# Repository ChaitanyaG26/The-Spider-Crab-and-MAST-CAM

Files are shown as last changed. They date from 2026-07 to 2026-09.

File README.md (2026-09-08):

# The Spider-Crab and MAST-CAM
A rover (rough "Perserverance-replica") equipped with rocker bogie (with a differential bar) suspension, capable of object detection + avoidance (with the RPi AI camera/US-100 sensors), remote control, and autonomous travel (with an onboard GPS). __THERE IS NO PCB ON THIS BUILD. IT IS SOLDERLESS.__ Modeled around the STS-3215 servo. (Special thanks here to Logan Wheatcroft for helping me spell "attach" and getting this project reviewed, and yes, his research project IS real despite what he may say, and of course, SWN from Print Legion for printing everything, alongside my brother -- who "singlehandedly got my project reviewed").

## Table of Contents
- [The Spider-Crab and MAST-CAM](#the-spider-crab-and-mast-cam)
- [Table of Contents](#table-of-contents)
- [Hack-Club Required Q&A](#hack-club-required-qa)
- [Full Assembly Screenshots](#full-assembly-screenshots)
- [BOM](#bom)
- [Printing Instructions](/docs/printing.md)
- [Setting Up The Pi](/docs/electronics-setup.md)
- [Wiring Instructions](/docs/wiring.md)
- [Assembly Instructions](/docs/assembly.md)

## Hack-Club Required Q&A
So, let's see:
1. What is this? This is designed to be a hyper-mobile rover that is capable of autonomous driving, pathfinding (because it is combined with a GPS), and providing camera footage. I hope that I will be able to modify it for usage out of one of two scenarios: 1. hopefully rescue missions on debris/unstable territory (since the rover is pretty lightweight, weighing in at just about 4.5 kgs, and is theoretically capable of some crazy feats as long as the net tractive force is stable), or 2. conducting BAER assessment (providing photos to researchers about theoretically dangerous territories subject to wildfires). If the rover lacks mobility in practice, I will probably move towards the latter concept, in which case I have plans of adding six "sample"-collecting add-ons to be attached to each wheel.
2. Why did I build this? Well, I've always been interested in Aerospace, and I've always thought the Perserverance rover was magical. I'm part of a drone team, and since we just built a drone that was not much unlike Ingenuity, I wondered if I could "complete" the duo here on Earth entirely from my own vision. This rover is the result of that work. I've gone through four separate unique versions of this rover (and even more "micro-versions" where I had to redesign parts inside each version to keep up with out-of-stock products and so on), but the hope is that this final rover will be just as mobile as the rover on Mars, MUCH faster (hopefully going at a mile an hour), WAY less power efficient (but to be fair, I don't exactly have the greatest parts at my disposal), and a final cost JUST under $1000 (so it's affordable), and accessible (meaning it is COMPLETELY idiot-proof -- I should be a good test subject for this, since I have not dealt with PCB design in the LEAST --, and has NO soldering/pcbs involved).

## Full Assembly Screenshots
Okay, before we get started, let's get a few hero renders out of the way.







Eventually, when I build this, I should be able to attach a few "normal" photos of how it'll look. [You may find the final assembly here.](https://cad.onshape.com/documents/4276ee27674d5cd4437829d8/w/b68ed14a30814a824c43fb7e/e/30365733099079a1b69868d1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)

## BOM
Find the BOM above in the attached files.
Or, alternatively, here it is below:

| Quantity | Item | Description | Source | Cost |
| :--- | :---: | :---: | :---: | ---: |
| 24 | [JST 3-Pin to Male](https://www.adafruit.com/product/3893) | Allows for power-injection to the Feetech servos. | Adafruit |  $30.00  |
| 3 | [US-100 Ultrasonic Sensor](https://www.adafruit.com/product/4019) | Allows the rover to navigate terrain/avoid objects. | |  $20.85  |
| 1 | [Pi Camera Cable, 500mm](https://www.adafruit.com/product/5820) | Allows the camera module to freely move. | |  $2.50  |
| 1 | [Raspberry Pi AI Camera*](https://www.adafruit.com/product/6009) | Allows the rover to have object detection/recognition capabilities. | |  $77.00  |
| 1 | [Raspberry Pi 5, 8GB*](https://aaawave.com/products/raspberry-pi-5-development-broad?variant=51441087152449) | The "brains" of the rover. | AAAWave |  $161.63  |
| 1 | [Bus Servo Adapter](https://www.ebay.com/itm/206185697206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) | Allows for the Pi to communicate with the serial bus servos. | eBay |  $12.23  |
| 1 | [microSD Card, A2/V30](https://www.aliexpress.us/item/3256807313581295.html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) | Stores the OS/Firmware on the Pi. | AAAWave |  $29.81  |
| 6 | [Feetech STS3215](https://www.aliexpress.us/item/3256808670629323.html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) | Allows for the rover to move (both its wheels and the camera). | Aliexpress |  $268.65  |
| 1 | [Soldering Iron, HS02A](https://www.aliexpress.us/item/3256809503553320.html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) | Necessary to attach the heat-set inserts, tool. | |  $50.57  |
| 1 | [Hot Air Gun](https://www.aliexpress.us/item/3256810350606440.html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) | Necessary to secure the shrink tubing to properly insulate wires. | |  $7.65  |
| 1 | [Heat Shrink Tubing](https://www.aliexpress.us/item/3256807959988149.html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) | Necessary to electrically insulate certain wires. | |  $6.97  |
| 1 | [WAGO 221-415](https://www.aliexpress.us/item/3256811952946871.html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) | Necessary to proper distribute power as desired. | |  $8.60  |
| 1 | [USB-C/Screw Terminal](https://www.aliexpress.us/item/3256812221028465.html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) | Necessary to provide the RPi power through bare wires. | |  $1.77  |
| 2 | [1M, 12AWG Wire](https://www.aliexpress.us/item/3256808222999562.html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) | Facilitates an electrical connection across parts. | |  $10.86  |
| 1 | [RPi 5, Active Cooler](https://www.amazon.com/dp/B0CW164TCW?ref_=ppx_hzod_title_dt_b_fed_asin_title_0_0) | Allows for smooth Pi operation, prevents overheating. | Amazon |  $9.90  |
| 1 | [12V/30A Daiertek Switch](https://www.amazon.com/dp/B0FL6B75PM?ref_=ppx_hzod_title_dt_b_fed_asin_title_1_0) | A manual power switch for the rover. | |  $29.99  |
| 1 | [20A ANL Fuse](https://www.amazon.com/dp/B01LXQWZ7L?ref_=ppx_hzod_title_dt_b_fed_asin_title_1_1) | Protects electronics downstream. | |  $12.99  |
| 1 | [VK-162 GPS](https://www.amazon.com/dp/B078Y52FGQ?ref_=ppx_hzod_title_dt_b_fed_asin_title_1_2) | Allows the Raspberry Pi to navigate via GPS. | |  $18.98  |
| 1 | [Rod Ends (Small)](https://www.amazon.com/dp/B0828TMYLD?ref_=ppx_hzod_title_dt_b_fed_asin_title_2_0) | Allow for the rocker-bogie suspension to function. | |  $9.99  |
| 1 | [M3x5.7 Heat Set Inserts](https://www.amazon.com/dp/B0D7M4WWBW?ref_=ppx_hzod_title_dt_b_fed_asin_title_2_1) | Allow for the printed parts to be fastened together. | |  $6.47  |
| 1 | [2300 PCS, M3 Screws Kit](https://www.amazon.com/dp/B0FGX859K8?ref_=ppx_hzod_title_dt_b_fed_asin_title_2_2) | Necessary hardware for the assembly to be possible. | |  $21.99  |
| 1 | [Flanged Ball Bearing](https://www.amazon.com/dp/B0G1B7H48R?ref_=ppx_hzod_title_dt_b_fed_asin_title_2_3) | Necessary hardware for the rocker-bogie to be possible. | |  $8.69  |
| 1 | [Jumper Cables](https://www.amazon.com/dp/B07GD2PGY4?ref_=ppx_hzod_title_dt_b_fed_asin_title_2_4) | Allow for power-injection to the daisy-chained servos. | |  $8.99  |
| 2 | [20A/300W Buck Converter](https://www.amazon.com/dp/B099S2VQ2Q?ref_=ppx_hzod_title_dt_b_fed_asin_title_0_0) | Allow for the 12V battery to transfer power downstream. | |  $18.99  |
| 1 | [PTFE/Plumber's Tape](https://www.amazon.com/dp/B091913Z7F?ref_=ppx_hzod_title_dt_b_fed_asin_title_1_0) | Facilitate the physical "bushing" inside the wheels. | |  $3.99  |
| 1 | [12V, 15Ah LiFePO4](https://www.amazon.com/dp/B0CSWMF35Q?ref_=ppx_hzod_title_dt_b_fed_asin_title_1_1) | Powers the rover (hopefully for 2+ hours). | |  $74.99  |
| 1 | [Female Spade Connectors](https://a.co/d/03C3n3lU) | Allow for solderless power supply. | |  $6.99  |
| 1 | [Digital Multimeter](https://www.amazon.com/dp/B08CX9W7G3?ref_=ppx_hzod_title_dt_b_fed_asin_title_0_0) | Checking if the electronic components are viable. | |  $38.43  |
| 1 | [Ring Lugs Set](https://www.amazon.com/dp/B0F99P7SGT?ref_=ppx_hzod_title_dt_b_fed_asin_title_1_0) | Allow for wires to be crimped onto the ANL fuse. | |  $13.99  |
| 1 | [12V LiFePO4 Charger](https://www.amazon.com/dp/B0G3ZNWC4J?ref_=ppx_hzod_title_dt_b_fed_asin_title_1_1) | Charges the battery. | |  $12.19  |
| 1 | [M4x10mm Screws](https://www.amazon.com/dp/B0FH2T8PD1?ref_=ppx_hzod_title_dt_b_fed_asin_title_0_0) | Necessary hardware for the assembly to be possible. | |  $4.30  |
| 1 | [ASA Filament,<br>2kgs (1.2ish needed)](https://www.amazon.com/dp/B0G2L8HKB8?ref_=ppx_hzod_title_dt_b_fed_asin_title_0_0) | Filament for prints. | |  $37.87  |
| 1 | [TPU 95A Filament,<br>1kg (0.8ish needed)](https://www.amazon.com/dp/B07VDP2S3P?ref_=ppx_hzod_title_dt_b_fed_asin_title_0_0) | Filament for prints. | |  $25.97  |
| 1 | [Crimpling "Plier"](https://www.amazon.com/dp/B073YG65N2?ref=ppx_yo2ov_dt_b_fed_asin_title) | Necessary to properly attach the solderless lugs/terminals. | | $8.99 |
| Total: |  |  (with taxes and shipping)  |  |  $1,121.90  |

*Note that for funding purposes, since the Pi and the AI camera are overkill, you can try getting a Pi 4/normal camera module 3 for these. The total cost with these instead would be $994.97ish (which, depending on the version/website you look at, is under $1k!!), and excluding the Pi 5/AI camera is $894.97.

Recommended additional common supplies (double-check you have these):
1. An official raspberry pi 5 power supply (27W).
2. A 12V power supply (preferably 2-3A or less) with a DC5521 power jack.
3. USB to USB-C cable (or a USB to a USB-C female port, and then a USB-C to a USB-C).
4. Micro-HDMI to HDMI cable (this is HIGHLY recommended for setup, because a monitor makes everything easier, although THEORETICALLY you could set up the Pi completely headlessly via SSH).
5. Tape/ruler/marker/etc (these are helpful in construction).

[To be updated as the build proceeds].

## [Printing Instructions](docs/printing.md)
Follow the link above. A quick teaser of what is to come:


## [Setting Up The Pi](docs/electronics-setup.md)
Follow the link above. Another quick teaser:


## [Wiring Instructions](docs/wiring.md)
This is going to be updated once I finalize the wiring, but a teaser as of right now:


## [Assembly Instructions](docs/assembly.md)
[To be created].

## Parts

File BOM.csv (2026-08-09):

Quantity | Item | Description | Manufacturer | Link | Total Cost
24 | JST PH 2mm 3-Pin to Male | Allows for power-injection to the Feetech servos. | Adafruit | https://www.adafruit.com/product/3893 | $ 144.95
3 | US-100 Ultrasonic Sensor | Allows the rover to navigate terrain/avoid objects. |  | https://www.adafruit.com/product/4019
1 | Raspberry Pi Camera Cable, 500mm | Allows the camera module to freely rotate across its axes of freedom. |  | https://www.adafruit.com/product/5820
1 | Raspberry Pi AI Camera | Allows the rover to have object detection/recognition capabilities. |  | https://www.adafruit.com/product/6009
1 | Raspberry Pi 5, 8GB | The "brains" of the rover. | AAAWave | https://aaawave.com/products/raspberry-pi-5-development-broad?variant=51441087152449 | $ 161.63
1 | Waveshare Serial Bus Driver | Allows for the Pi to communicate with the serial bus servos. | eBay | https://www.ebay.com/itm/206185697206?emsid=e11412.m144671.l197929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 | $ 12.23
6 | Feetech STS3215 | Allows for the rover to move (both its wheels and the camera). | Aliexpress | https://www.aliexpress.us/item/3256808670629323.html | $ 404.07
1 | Soldering Iron, HS02A | Necessary to attach the heat-set inserts, tool. |  | https://www.aliexpress.us/item/3256809503553320.html
1 | Hot Air Gun | Necessary to secure the shrink tubing to properly insulate wires. |  | https://www.aliexpress.us/item/3256810350606440.html
1 | Heat Shrink Tubing Kit | Necessary to electrically insulate certain wires. |  | https://www.aliexpress.us/item/3256807959988149.html
1 | WAGO 221-415 Lever Nuts | Necessary to proper distribute power as desired. |  | https://www.aliexpress.us/item/3256811952946871.html
1 | Crimpling "Plier" | Necessary to properly attach the solderless lugs/terminals. |  | https://www.aliexpress.us/item/2251832197019276.html
1 | USB-C to Screw Terminals | Necessary to provide the RPi power through bare wires. |  | https://www.aliexpress.us/item/3256812221028465.html
2 | 1M, 12AWG Wire | Facilitates an electrical connection across parts. |  | https://www.aliexpress.us/item/3256808222999562.html
1 | RPi 5, Active Cooler | Allows for smooth Pi operation, prevents overheating. | Amazon | https://www.amazon.com/dp/B0CW164TCW?ref_=ppx_hzod_title_dt_b_fed_asin_title_0_0 | $ 162.99
1 | 12V, 30A Daiertek Switch | A manual power switch for the rover. |  | https://www.amazon.com/dp/B0FL6B75PM?ref_=ppx_hzod_title_dt_b_fed_asin_title_1_0
1 | 20A ANL Fuse (and Holder) | Protects electronics downstream. |  | https://www.amazon.com/dp/B01LXQWZ7L?ref_=ppx_hzod_title_dt_b_fed_asin_title_1_1
1 | VK-162 GPS | Allows the Raspberry Pi to navigate via GPS. |  | https://www.amazon.com/dp/B078Y52FGQ?ref_=ppx_hzod_title_dt_b_fed_asin_title_1_2
1 | Rod Ends (Small) | Allow for the rocker-bogie suspension to function. |  | https://www.amazon.com/dp/B0828TMYLD?ref_=ppx_hzod_title_dt_b_fed_asin_title_2_0
1 | 120PCS, M3x5.7 Heat Set Inserts | Allow for the printed parts to be fastened together. |  | https://www.amazon.com/dp/B0D7M4WWBW?ref_=ppx_hzod_title_dt_b_fed_asin_title_2_1
1 | 2300 PCS, M3 Screws Kit | Necessary hardware for the assembly to be possible. |  | https://www.amazon.com/dp/B0FGX859K8?ref_=ppx_hzod_title_dt_b_fed_asin_title_2_2
1 | Flanged Ball Bearing | Necessary hardware for the rocker-bogie to be possible. |  | https://www.amazon.com/dp/B0G1B7H48R?ref_=ppx_hzod_title_dt_b_fed_asin_title_2_3
1 | Breadboard Jumper Wires | Allow for power-injection to the daisy-chained servos. |  | https://www.amazon.com/dp/B07GD2PGY4?ref_=ppx_hzod_title_dt_b_fed_asin_title_2_4
2 | Adjustable DC Buck Converter | Allow for the 12V battery to transfer power downstream. |  | https://www.amazon.com/dp/B099S2VQ2Q?ref_=ppx_hzod_title_dt_b_fed_asin_title_0_0 | $ 129.46
1 | PTFE/Plumber's Tape | Facilitate the physical "bushing" inside the wheels. |  | https://www.amazon.com/dp/B091913Z7F?ref_=ppx_hzod_title_dt_b_fed_asin_title_1_0
1 | 12V, 15Ah LiFePO4 | Powers the rover (hopefully for 2+ hours). |  | https://www.amazon.com/dp/B0CSWMF35Q?ref_=ppx_hzod_title_dt_b_fed_asin_title_1_1
1 | Spade Terminal Connectors | Allow for power to be transmitted from the battery downstream solderlessly. |  | https://www.amazon.com/dp/B0B4H54KPS?ref_=ppx_hzod_title_dt_b_fed_asin_title_2_0
1 | Digital Multimeter | Checking if the electronic components are viable. |  | https://www.amazon.com/dp/B08CX9W7G3?ref_=ppx_hzod_title_dt_b_fed_asin_title_0_0 | $ 38.43
1 | Ring Lugs Set | Allow for wires to be crimped onto the ANL fuse. |  | https://www.amazon.com/dp/B0F99P7SGT?ref_=ppx_hzod_title_dt_b_fed_asin_title_1_0
1 | 12V LiFePO4 Charger | Charges the battery. |  | https://www.amazon.com/dp/B0G3ZNWC4J?ref_=ppx_hzod_title_dt_b_fed_asin_title_1_1
1 | M4x10mm Screws | Necessary hardware for the assembly to be possible. |  | https://www.amazon.com/dp/B0FH2T8PD1?ref_=ppx_hzod_title_dt_b_fed_asin_title_0_0 | $ 4.30
1 | ASA Filament, 2kgs (1.2ish needed) | Filament for prints. |  | https://www.amazon.com/dp/B0G2L8HKB8?ref_=ppx_hzod_title_dt_b_fed_asin_title_0_0 | $ 37.87
1 | TPU 95A Filament, 1g (0.8ish needed) | Filament for prints. |  | https://www.amazon.com/dp/B07VDP2S3P?ref_=ppx_hzod_title_dt_b_fed_asin_title_0_0 | $ 25.97
Total: |  |  |  |  | $ 1,121.90

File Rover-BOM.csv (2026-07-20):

Quantity | Item | Description | Manufacturer | Link | Cost (No Tax/Shipping)
12 | Servo | Powers the wheels and the camera module. | WOWROBO | https://shop.wowrobo.com/products/feetech-sts3215-servo-12v-30kg-high-torque-servo-for-so-arm100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 | $ 171.88
1 | RPi5/8GB | Powers the camera module, controls the rover. The "brains." | AAAWave | https://aaawave.com/products/raspberry-pi-5-development-broad?variant=51441087152449 | $ 150.00
1 | MicroSD | High-powered SD card for video streaming. | Sandisk | https://www.sandisk.com/products/memory-cards/microsd-cards/sandisk-extreme-uhs-i-microsd?sku=SDSQXAH-064G-GN6MA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 | $ 25.99
1 | RPi Active Cooler | Provides cooling (improving performance) to the RPi. | Waveshare | https://www.waveshare.com/pi5-active-cooler-b.htm | $ 4.99
1 | Servo Driver HAT | Allows the RPi to control the servos. |  | https://www.waveshare.com/bus-servo-driver-hat-a.htm | $ 18.99
1 | RPi AI Camera | Allows the RPi to run object detection/livestreaming. | Adafruit | https://www.adafruit.com/product/6009?src=raspberrypi | $ 77.00
1 | Camera Cable - 500mm | Extends the camera module's range. |  | https://www.adafruit.com/product/5820 | $ 2.50
3 | US-100 Sensor | Allows the RPi to run object avoidance. |  | https://www.adafruit.com/product/4019 | $ 20.85
1 | Stacking Header, GPIO | Allows the HAT to be attached onto the Pi alongside the Active Cooler. |  | https://www.adafruit.com/product/2223 | $ 2.95
12 | Male to JST-PH Wires | Allows for the solderless wiring (acting as a breakout board for power-injection). |  | https://www.adafruit.com/product/3893 | $ 15.00
12 | Female to JST-PH | Same role as the male wires, composite. | Electromaker | https://www.electromaker.io/shop/product/stemma-jst-ph-3-pin-to-female-socket-cable-200mm | $ 15.00
1 | Ball Bearings | Facilitate the rocker-bogie's rotational freedom. | Amazon | https://www.amazon.com/uxcell-F6901ZZ-Flanged-Bearings-Shielded/dp/B0G1B7H48R?sp_csd=d2lkZ2V0TmFtZT1zcF9tdGY | $ 7.82
1 | VK-162 | Allow the RPi to gain GPS-based autonomous capabilities. |  | https://www.amazon.com/Navigation-External-Receiver-Raspberry-Geekstory/dp/B078Y52FGQ | $ 17.98
1 | LiFePO4 12V 15Ah Battery | Powers the rover. |  | https://www.amazon.com/12-8V-20Ah-LiFePO4-Battery-Lithium/dp/B0DHKS1GK6 | $ 53.19
1 | LiFePO4 Charger | Charges the battery. |  | https://www.amazon.com/dp/B078962VRM?s=automotive&sp_csd=d2lkZ2V0TmFtZT1zcF9kZXRhaWxfdGhlbWF0aWM | $ 25.07
1 | WAGO 221-415 (25 Pack) | Facilitate the solderless connections with the power gauge wire and the Male/Females. |  | https://www.amazon.com/WAGO-221-415-Lever-Nuts-5-Conductor-Connectors/dp/B07WC2XBMK | $ 17.99
1 | Breadboard Jumper Wires Set | To extend the Male/Female JST-PH wires. |  | https://www.amazon.com/EDGELEC-Breadboard-Optional-Assorted-Multicolored/dp/B07GD2PGY4?s=industrial | $ 8.99
1 | Heat Shrink Tubing Set | Allow for the solderless collections to be solid. |  | https://www.amazon.com/Eventronic-560-Heat-Shrink-Tubing/dp/B0DK15C58W?s=hi&sp_csd=d2lkZ2V0TmFtZT1zcF9hdGY | $ 13.59
1 | Mini Heat Gun | Combine with the Heat Shrink Tubing |  | https://www.amazon.com/QWORK-Shrink-Shrinking-Wrapping-Embossing/dp/B09NDCCW29?s=hi | $ 8.72
2 | 20A 300W Adjustable Buck Converter | Allows for the power source to safely distribute power to the Pi/Servos. |  | https://www.amazon.ca/XLX-High-Power-Converter-Adjustable-Protection/dp/B081X5YX8V | $ 31.98
1 | 20A ANL Fuse | Protects the inner circuitry. |  | https://www.amazon.com/RENOGY-30A-ANL-Fuse-Holder/dp/B01LXQWZ7L | $ 12.99
1 | Spade Terminal Connectors | Allow for a solderless connection to the battery. |  | https://www.amazon.com/Feggizuli-Connectors-Connector-Terminals-Electrical/dp/B0B4H54KPS | $ 7.69
1 | 12 Gauge Wire | Allow for power streaming over long-distance power injection. |  | https://www.amazon.com/Voltage-Automotive-Primary-Security-Electrical/dp/B0D97CJYY7?rnid=1243644011 | $ 11.99
1 | Rod-End Set | Allows for the Differential Mechanism to function. |  | https://www.amazon.com/Que-T-10pcs-Metal-Crawler-Silver/dp/B0828TMYLD?s=toys-and-games | $ 9.99
1 | M3 Screw/Nut Set | Required for the multipart assembly. |  | https://www.amazon.com/Fgruh-2300PCS-M3-Assortment-Washers/dp/B0FGX859K8?sp_csd=d2lkZ2V0TmFtZT1zcF9hdGY | $ 21.99
1 | Plumber's Tape | Alternative to bushing, bridge the ASA with low frictional losses. |  | https://www.amazon.com/Inches-Plumbers-Plumbing-Plumber-Sealing/dp/B0919T7JV1?sp_csd=d2lkZ2V0TmFtZT1zcF9hdGY | $ 7.39
1 | Heat-Set Inserts | Required for the multipart assembly. |  | https://www.amazon.com/Threaded-Inserts-M3x5-7x4-6-Soldering-Materials/dp/B0D7M4WWBW | $ 6.27
1 | Soldering Tin | Required for the stacking header soldering. |  | https://www.amazon.com/MAIYUM-63-37-Solder-Electrical-Soldering/dp/B075WB98FJ?sp_csd=d2lkZ2V0TmFtZT1zcF9hdGY | $ 8.99
1 | Soldering Iron | Required for the Heat-Set Inserts and the Soldering. | Aliexpress | https://www.aliexpress.us/item/3256809503461511.html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 | $ 31.38
Total: |  |  |  |  | $ 809.16
Total (*with taxes and shipping): |  |  |  |  | $ 1,000.00
Total (*with taxes and shipping AND prints): |  |  |  |  | $ 1,350.00

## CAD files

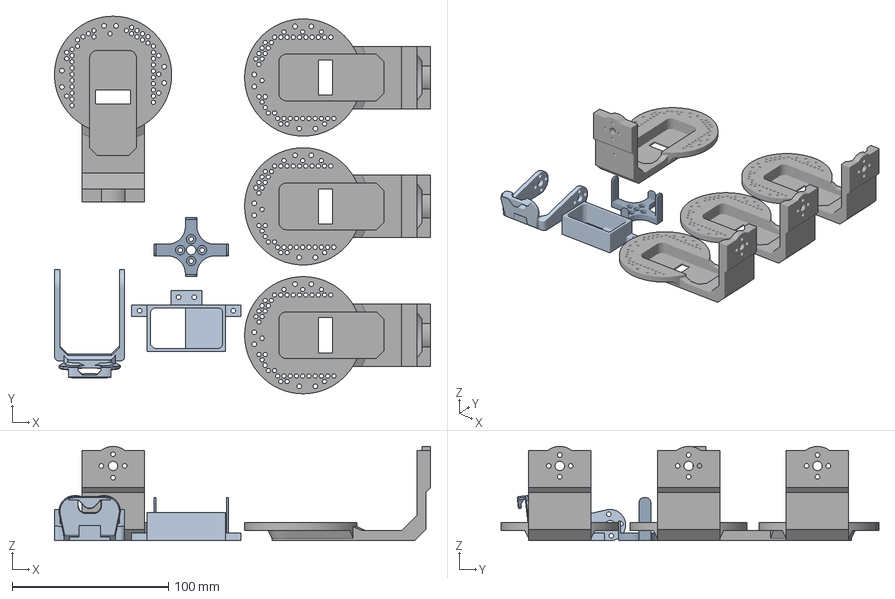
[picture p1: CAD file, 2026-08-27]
3MF Files/ASA_#4_20%_3d-cubic_2walls.3mf
240.7 x 241.7 x 60.3 mm
Servo Base
Arm x 4
S-S/C
C-S/C

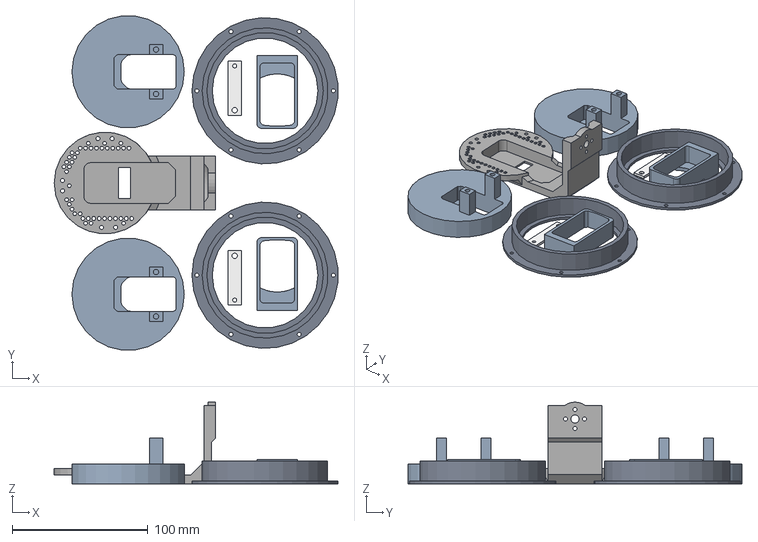
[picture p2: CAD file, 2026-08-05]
STEP Files/Build Plates/Build_Plate-1-and-2-ASA.step
209.1 x 246.3 x 60.3 mm

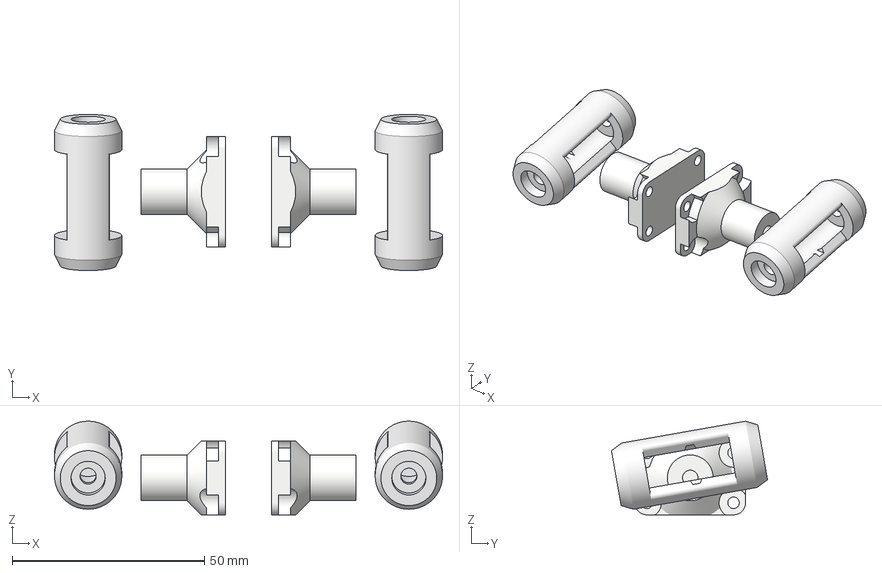
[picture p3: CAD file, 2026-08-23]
3MF Files/ASA_#9_50%_3d-cubic_4walls.3mf
100.9 x 40.6 x 24.4 mm
CRBC x 2
DRE/C x 2

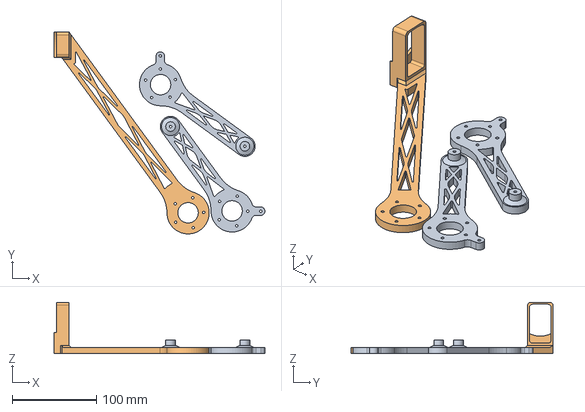
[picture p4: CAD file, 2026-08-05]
STEP Files/Build Plates/Build_Plate-7-ASA.step
250.8 x 239.9 x 61.1 mm

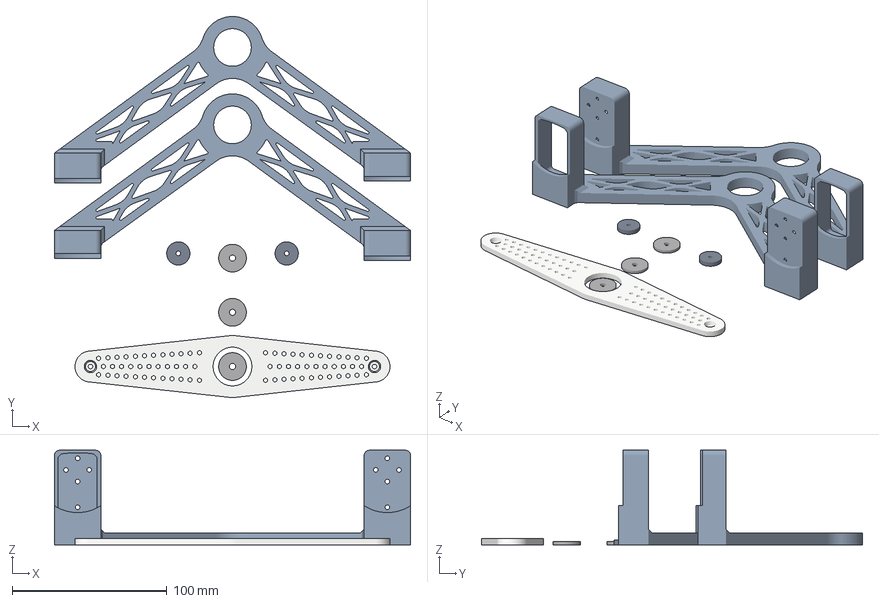
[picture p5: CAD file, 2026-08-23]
3MF Files/ASA_#6_20%_3d-cubic_2walls.3mf
230.0 x 246.0 x 61.1 mm
Bogie/R
BB/C/F x 3
BBSL/F
Bogie/L
BBSR/F
Differential Bar

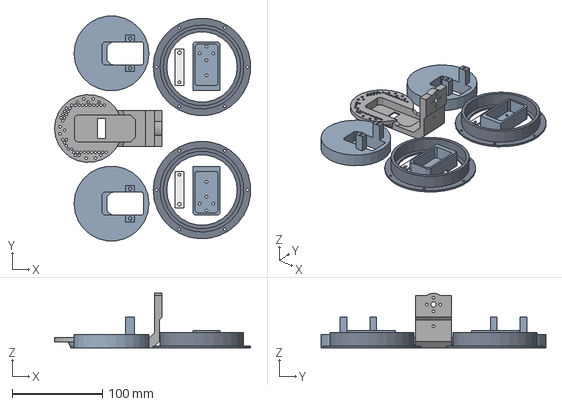
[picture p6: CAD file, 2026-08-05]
STEP Files/Build Plates/Build_Plate-3-ASA.step
216.6 x 248.3 x 60.3 mm

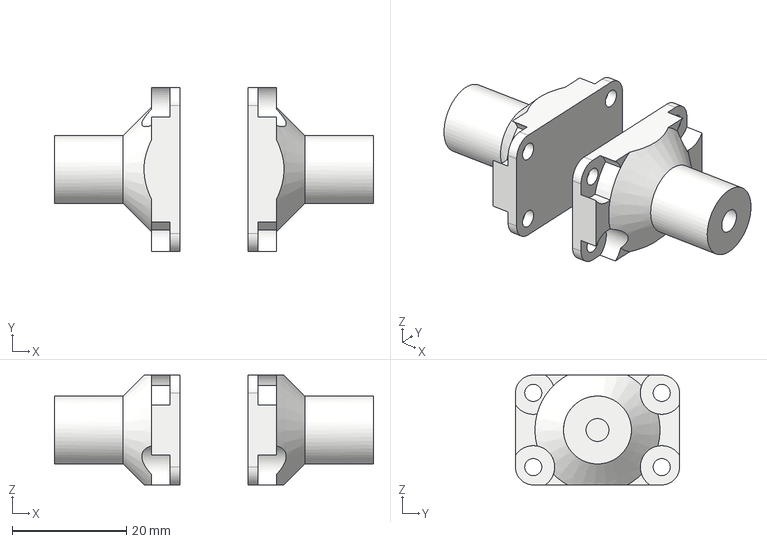
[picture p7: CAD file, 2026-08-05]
STEP Files/Build Plates/Build_Plate-9-ASA.step
55.9 x 28.7 x 19.2 mm

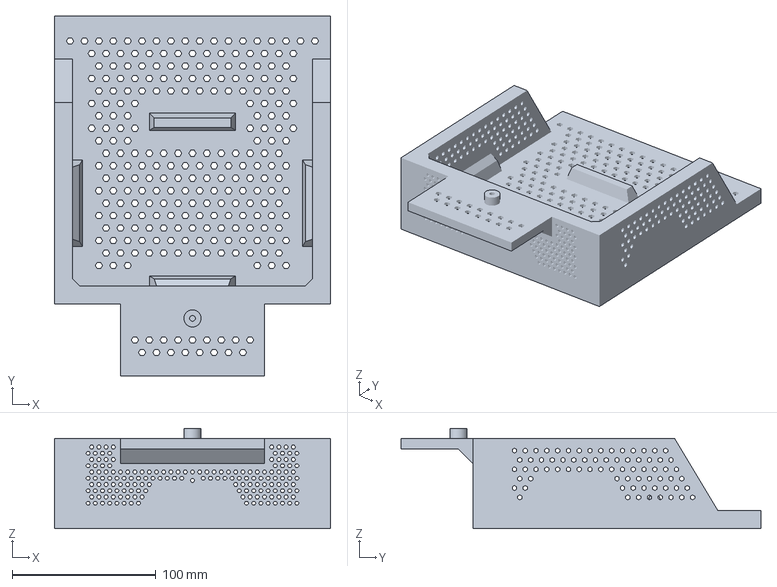
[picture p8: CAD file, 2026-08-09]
3MF Files/ASA_#5_15%_3d-cubic_2walls.3mf
191.9 x 250.0 x 69.7 mm

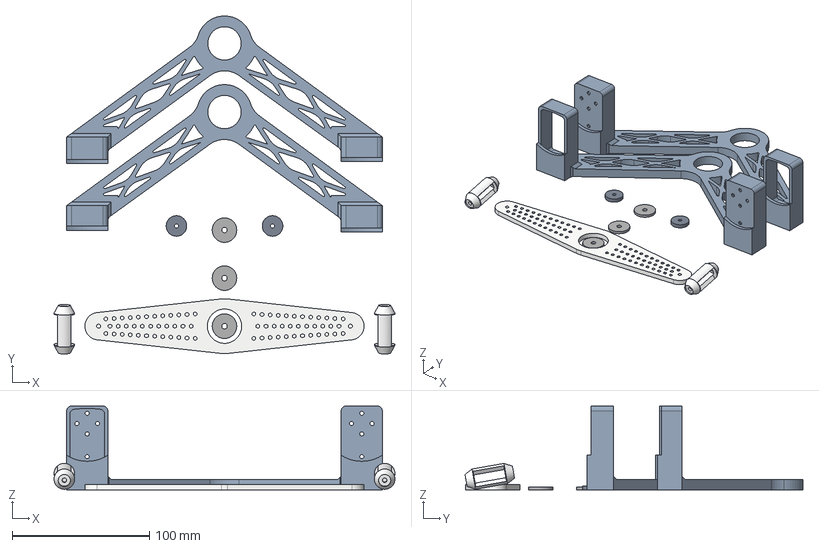
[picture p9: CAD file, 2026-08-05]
STEP Files/Build Plates/Build_Plate-6-ASA.step
248.4 x 246.2 x 61.1 mm

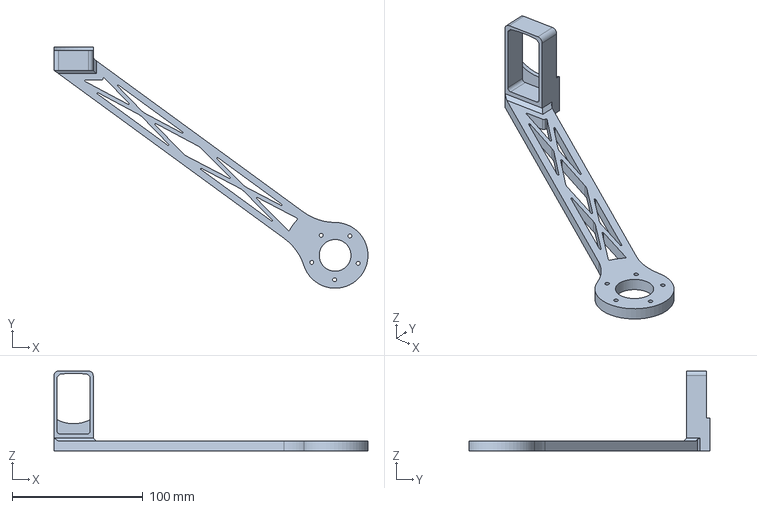
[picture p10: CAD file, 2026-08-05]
STEP Files/Build Plates/Build_Plate-8-ASA.step
239.9 x 184.5 x 61.1 mm

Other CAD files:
3MF Files/TPU_#1_15%_gyroid_6wallsmodifiers_2walls.3mf
STEP Files/Build Plates/Build_Plate-4-ASA.step
3MF Files/ASA_#3_20%_3d-cubic_2walls.3mf
3MF Files/ASA_#7_20%_3d-cubic_2walls.3mf
3MF Files/ASA_#2_20%_3d-cubic_2walls.3mf
3MF Files/ASA_#1_20%_3d-cubic_2walls.3mf
3MF Files/ASA_#8_20%_3d-cubic_2walls.3mf

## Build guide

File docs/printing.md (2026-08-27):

## Printing Instructions

PLEASE PLEASE PLEASE make it easy on yourself and use the 3MF **NOT** the STEP files for actually uploading onto a slicer.
Whenever you load the part, make sure that if you get the following screen, you click **yes**:


If you look at the naming convention for each 3MF files, it is clearly explained what settings are recommended (IE, ASA_#9_20%_3d-cubic\_4walls should be printed in ASA at 20% infill in a cubic sparse infill pattern with 4 walls). Now, this does get more complicated with the TPU. The TPU 3MF files include simple cylinders positioned around holes. These cylinders are modifiers. ***While the rest of the print is to be at 15% gyroid infill with 2 walls, these modifiers should be changed to SIX walls.*** This is VERY crucial. Heat Set Inserts are very annoying with TPU (as I've heard), and for them to be properly fastened/secured, the TPU must be made rigid. To save your time and filament whilst making heat-sets viable, these modifiers are meant to circle each cylindrical hole, providing enough material for the heat-set inserts to properly bite into the thermoplastic. If everything goes right, you should expect around 545g worth of filament being used for TPU\_1. Keep supports on for all prints.

### Adding Modifiers to a Print:


Note that the provided settings are the basic settings. If you have other settings for supports, etc, you may use those (as those do not impact strength).

IN TOTAL YOU MAY EXPECT: 817.79g TPU being used (this is with supports) over 51.64 hours of printing. 1107.18g ASA being used (this is also with supports) over 56.67 hours of printing, for a total of around 108.31 hours of printing.

Tolerances are in-built into the prints, so long as everything is printed in the right material (ASA or TPU), as outlined. Remember, any other materials would either be more expensive alternatives, or less viable ones (ie, TPU is the best filament here because it is relatively common, flexible, but has a high temperature deflection point relative to the use-case the rover is ideal for, and ASA is the best rigid common filament with another reasonable temperature deflection point). You can see the overall assembly at this [link](https://cad.onshape.com/documents/4276ee27674d5cd4437829d8/w/b68ed14a30814a824c43fb7e/e/30365733099079a1b69868d1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). navigate to "The Spyder-Crab", and then the assembly of the same name), and simply hide the relevant objects to see precisely where everything goes.

Since there's so many parts (600 by my estimation), I will NOT be going over how each of the parts fit, although I believe most of it is obvious: in general, holes of diameter 4mm have a heat-set insert, holes of diamter 3mm allow for M3 screws to be passed, and so on. There are other specific cut-outs for flanged ball bearings (and so on for other parts, such as the rod-end).

Photos of the print plates:
### ASA #1 AND #2 (remember, these are the EXACT same plate, but one of the two needs to be printed twice or **BOTH NEED TO BE PRINTED ONCE EACH**):


### ASA #3:


### ASA #4:


### ASA #5:


### ASA #6:


### ASA #7:


### ASA #8:


### ASA #9:


### TPU #1:


### TPU #2:


Eventually, I will make a complete tutorial for how the rover will be built (step-by-step), with photos (or a video).

[Go back home.](/README.md)

[Onto the next tutorial!](/docs/electronics-setup.md)

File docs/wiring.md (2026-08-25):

## Wiring Instructions
TL;DR WIRING DIAGRAMS: I would HIGHLY recommend reading the next bits of text for a full tutorial on how to wire everything, but here are three "brief" wiring diagrams showcasing how everything will work.
Schematic1
Schematic2


THE ROVER IS COMPLETELY SOLDERLESS. IT IS DESIGNED TO NOT REQUIRE A PCB, BUT RATHER EASILY SOURCED PARTS ONLINE. There is nothing but a bit of cutting wires/sliding them into screw terminals or WAGO lever nuts. The rough diagram can be seen in the following image, subject to change (as soon as I build it and test it myself).





##### A GENERAL WARNING AND/OR A WORD TO NOTE BEFORE WE BEGIN. UNLESS YOU ARE TESTING YOUR CIRCUIT, DISCONNECT IT FROM THE BATTERY. IT DOES NOT MATTER IF THE POWER SWITCH IS OFF, OR EVEN THE BUCK CONVERTER'S SWITCH, IF THE BATTERY IS CONNECTED POWER CAN BE STORED IN THE BUCK CONVERTER'S CAPACITOR AND A) POWER WILL DRAIN FASTER THAN YOU THINK AND B) YOU MIGHT HAVE SPARKS WHILE YOU ATTACH YOUR COMPONENTS. WHENEVER YOU ATTACH SOMETHING, MAKE SURE THE POWER IS OFF. WHENEVER TURNING OFF POWER, START DOWNSTREAM UP (THE POWER SWITCH, THEN THE BUCK CONVERTER, THAN THE SPADE TERMINAL CONNECTORS THEMSELVES -- MAKING SURE TO TOUCH THE _PLASTIC_ NOT THE METAL TO RISK INJURY).

##### WHEN WORKING WITH STRIPPING THESE WIRES, I HIGHLY RECOMMEND USING THE STRIPPING TOOL TO MAKE AN INCISION THREE QUARTERS OF A FINGERNAIL FROM THE EDGE, AND THEN USING A SEPARATE BLADE TO FULLY REMOVE THE INSULATING PLASTIC LAYER (SINCE THE WIRE IS FINELY STRANDED, ANY MAJOR INCISION/TUGGING WITH THE WIRE STRIPPER WOULD SEVERELY DAMAGE THE WIRE BY REMOVING ITS STRANDS). I ALSO HIGHLY RECOMMEND SEATING EACH WIRE INTO THE YELLLOW ATTACHMENT AS MUCH AS POSSIBLE BEFORE CRIMPING ON THE BOTTOM PART (AND ON THE CENTER PART): IE, AS IN THE EXAMPLE BELOW, WHERE YOU CAN SEE __TWO__ MARKS FROM THE CRIMPING TOOL. I ALSO HIGHLY RECOMMEND TWIRLING THE WIRE A BIT (NOT TWISTING, SINCE THAT CAN ALSO DAMAGE THE WIRE, BUT "COMPACTING THEM" THROUGH SMALLER ROTATIONAL MOVEMENT) BEFORE SEATING INTO THE WAGO LEVER NUTS (WHERE THEY MUST BE PUSHED IN AS FAR IN AS POSSIBLE).



As you can see here, this is the rough wiring layout. Connect the battery to crimped spade terminal wires (6-12 gauge), connect the other end to an ANL fuse (with ring lugs, again, crimped), to the power switch and then the buck converter (set at 12V). Route the wire from the buck converter to three separate lines via the WAGO (respectively), to the Pi, and to the servo power lines. The rest of the diagram can be read as follows. Remember, there must be power injection with the servos on top of the star topography, as there would be significant browning near stall. This can be done by taking each male-JST connector, and directing that to a female-female wire, and leading that to another male-JST connector (keeping the ground and signal wires the same, but exchanging the hot/positive lead for a voltage line out of another WAGO lever nut. Once I build this, I will add photos and a detailed guide of how this can be accomplished (after all, right now this is just all theoretical). Soon, everything should be up! Right now, it is as bare-bones as it gets, but I should have this sorted out in just a little bit of time.

Okay, so getting started with wiring. Remember to charge your battery while you set up everything (I recommend cutting up a few wires and beginning to strip them while you wait for the battery to charge a bit, although it ships near 50% so you can also get started immediately on this starter circuit).
Note that I call this a "starter circuit." It has the exact same wiring layout as the official wiring for the rover, but you haven't gotten to that yet so this is simply an incremental test to ensure all the parts work. You are to use no more than 1M of the wire (because the remaining meter will be used for the actual rover).



This is the "end result" before power injection, which is a WHOLE issue in of itself. We'll work our way up to it.
Firstly, two wires need to be crimped with a female spade terminal so everything fits nicely. You can see the spade terminals as the small yellow flat things. One of these will connect to the battery's positive lead, one to the ground or negative one. The 20A ANL fuse will connect DIRECTLY to the battery's positive lead via one of the two wires above, while the GND wire will go down the battery into one of the buck converters (you have three, pick one and wire the GND to it's IN- screw terminal). Meanwhile, the other end of the ANL fuse will lead to the IN+ screw terminal. It is at this point, you may take your multimeter and place its red lead in the Voltage port (usually, multimeters have three ports, I recommend the one labeled something along the lines of "mA") and the black lead in the COM port



You may then place the red/positive lead into the OUT+ screw terminal and the black/negative lead into the OUT- screw terminal. Adjust CV (with a screwdriver) until you get a number roughly around 12V. This will serve as the power for your servo. Then, disconnect it when you are done.

Now, after that, your OUT+ lead of the buck converter will connect directly to one end of your Daiertek power switch (stripped, of course). The OUT- lead of the buck converter will connect directly to a GND wire. To understand why this specific layout was chosen, you need to understand: you provide power with the hot lead (the positive side) which carries current through an electric potential (a difference in voltage). Your goal, for all your electronics, is to make sure the positive lead wires somehow through a part, and then current flows from that positive lead to a negative or a ground port on that same part (where the voltage drop between the positive and negative ports allows for your current flow) and powers your device. Your power switch, by connecting to the buck converter and a WAGO lever nut, creates a "power rail," where any wire connected to that and a part which is similarly connected the "ground rail" (which your ground wire, which is connected to the OUT- of the buck converter and its own WAGO lever nut) and power can be provided. There are four red wires that connect to the power rail (ie, distribute power): the first is connected to another buck converter's IN+ lead (one that is to be used to provide power to the Raspberry Pi), and the other three are connected to their own WAGO lever nut (where, from each WAGO lever nut, power will be supplied to the appropriate servo, power injection, which can be seen through the image below). There are four black wires that connect to the ground rail, for the same reason: one acts as ground for the buck converter (and is inserter to the IN- lead), and three others connect to WAGO lever nuts to distribute ground to each servo. A common ground between the servo, after all, is necessary: the signals the bus servo adapter provides depend heavily on the voltage difference between the hot and ground leads, so a common voltage source MUST be accompanied by a common ground. You may fine tune the buck converter here so that you set 5V (or a slightly higher value, maybe 5.05 or 5.1V) as the CV on the second buck converter. The remaining slots are for wires that will directly go to the serial bus servos (not modeled here, but included in the image above, since I highly recommend NOT doing this step until you are absolutely positive everything is perfect).



You may wonder why this "power injection" is even necessary. In a daisy-chained configuration, all current required downstream is pulled upstream. When there is only one source, all this current goes through the VERY THIN JST PH wires (which are scarcely rated for more than 3A) and severe voltage browning occurs (ie, power is lost and suddenly, none of your servos are moving when you need them too). You need to make sure each servo gets its own independent power, and this reduces current through wire and ensures everything is fine. According to Waveshare, using the bus servo adapter in this way (to only run signals) is perfectly acceptable and extremely common (and thus, requires no major change in the code). The goal is, then, to make sure GND and the HOT leads are similarly _shared_ (ie, they are from the same source and maintain the same relative voltage difference, so that signals are accurate, which is why a single major power/gnd rail is created -- a "common" source allows for GND to be shared, and similarly for the HOT lead) and _individual_ (ie, no more than 2A every goes through ANY of the wires -- and if so, only for small amounts of time and VERY short distances).

Once you are done with your test circuit, I highly recommend waiting for prints and finishing [assembly](/docs/assembly.md), or at the VERY LEAST, finishing the [electronics set-up](/docs/electronics-setup.md) before beginning your official build so all of the wires can be cut to size and so you can properly place all of your electronics wherever you have space (or, for that matter, need to place them) on the build. Part of the reason for the MANY MANY MANY hex cut-outs (instead of simply reducing weight, something possible through a basic infill pattern such as 3d-honeycomb, cubic, or gyroid) is so electronics can be gently secured via screws and the multiple through holes.



But either way, I recommend starting in this manner, where your ANL fuse is parallel to the battery to save space and so your wires have minimal questionable contact and bending (no wire undergoes copious amounts of stress).

[Go back home.](/README.md)

[Onto the next tutorial!](/docs/assembly.md)

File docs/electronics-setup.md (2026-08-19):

## Setting Up The Pi
Note that this step should take place BEFORE the wiring is finalized (ie, the servos are included in the wiring), so everything can be tested properly and debugged (at least everything relevant to the coding), or, alternatively, before the wiring altogether.


A quick preview at what y'all are getting into.

Downloading the Imager.
Take your SD card, and plug into your computer. Try using either a computer with an SD card slot (with the microSD card in its SD card "sleeve") or get a USB-SD card reader.
1. Choose the Raspberry Pi 5 as the device.


2. Choose the default software (the Raspberry Pi 8GB can tolerate the 64-bit Raspberry Pi OS).


3. Choose your storage device as the SD card (which should be inserted into your computer).

4. Give the device a hostname/username/password you will remember. Write this down (it'll save you later).
5. If you get a dialog to connect to a network, provide your home wifi (and password, of course).
6. Enable SSH. You can enable a public SSH key, but I find that the password authentication setup is easier.
7. Flash your imager onto the appropriate storage device (the SD card you just plugged in).
8. Remove your SD card and plug that into the Raspberry Pi 5.
9. Connect the Raspberry Pi 5 to a monitor via a Micro-HDMI to an HDMI cable.

Setting up the Pi on Boot:
1. Once you are logged in, you can begin by setting up the VK-162. This is probably the easiest part of the setup.
    1. Plug in the VK-162 to a USB slot on the Raspberry Pi.
    2. Check the VK-162 is there with the command `ls /dev/ttyACM*` in the Raspberry Pi's CLI. The output            should be `dev/ttyACM0`
    3. Run `lsusb | grep -i "u-blox"` The result should be `Bus 003 Device 002: ID 1546:01a7 U-Blox AG`
       `[u-blox 7]` or an equivalent.
    4. Install gpsd:
       `sudo apt update`, then `sudo apt install -y gpsd gpsd-clients python3-gps`
    5. Configure gpsd:
       `sudo nano /etc/default/gpsd`, you must add: `DEVICES="/dev/ttyACM0"`, `GPSD_OPTIONS="-n"`, `START_DAEMON="true"`, and `USBAUTO="true"`
    6. Restart and test: `sudo systemctl restart gpsd`, then `cgps -s`  


2. If you want to, you can change the fan settings.
     1. Type `sudo nano /boot/firmware/config.txt` into the CLI.
     2. Scroll to the very bottom and add the lines below:
        `dtparam=fan_temp0=40000`
        `dtparam=fan_temp1=45000`
        `dtparam=fan_temp2=50000`
        `dtparam=fan_temp3=55000`
        `dtparam=uart0=on`
3. Setting up the Raspberry Pi AI Camera:
    1. The black side on the Pi is on the opposite side from the USB ports, whilst the black side on the Camera faces on the opposite side from the main camera module. Wire in this fashion. Tweezers are helpful.
    2. Run `sudo apt update && sudo apt full-upgrade`
    3. Run `sudo reboot`
    4. Run `rpicam-hello -t 0s --post-process-file /usr/share/rpi-camera-assets/imx500_mobilenet_ssd.json --viewfinder-width 1920 --viewfinder-height 1080 --framerate 30` This should return a live feed with post-processed object detection
    5. Run `rpicam-hello -t 0s --post-process-file /usr/share/rpi-camera-assets/imx500_posenet.json --viewfinder-width 1920 --viewfinder-height 1080 --framerate 30` This should return a live feed with post-processed pose detection.
    6. If you wish to change the focal length (and thus the focus), take the plastic knob, point the hollow end towards the camera module, press, and turn. Test out various focal lengths (but be careful as to not damage the electronic) through the hole until you find an appropriate one.
  


Kudos if your screen also looks something like this.

4. Setting up the __FIRST__ STS3215 Servo:
    1. Connect the servo horns to each servo. Usually, you can simply push into the toothed brass attachment until the horn is flush with the bottom and a click is heard. If the horn is refusing to be attached properly, use your thumb to push until you seat the horn a bit into the tooth (you can tell this is the case if you leave your hand and the horn doesn't move). Then, use your palm to connect it until a loud click is heard. The tolerances are so tight that the latter technique is often necessary (and in my experience the best one). Screw in everything (but leave a bit of leeway, so the horn is stable but the screw can still "wiggle" a bit).
    2. Make sure your bus servo adapter has the yellow jumpers set to "B" as labeled on the board. Find a USB to a USB-C cable. If you do not have one, a traditional USB to a USB-C female socket is acceptable when connected with a USB-C to a USB-C cable (in fact, the latter architecture is the one I chose). Attach the USB-C port to the bus servo adapter, and the USB to the Pi. Wire a servo through one of the JST ports to the servo's JST port (just be careful for the orientation). Plug in your bus servo adapter with a DC5521 power jack (connected to a 12V power supply for setup). Wait a few seconds, and then run `dmesg | tail -1`. Remember this, this is the port you will use in Step 8.
    3. Label the serial bus servo you have just plugged in with tape and a marker as 1. This is your servo ID (which must be unique for EACH of the 12 servos to allow for a functioning daisy-chain network). Label the rest of the 12 servos with similar numbering. You will label each servo with that ID during the following setup.
    4. Run `sudo apt update && sudo apt install unrar -y` This downloads a program capable of unzipping rar files on Linux (which is the format provided by Waveshare's ST-series servos).
    5. [Download the Waveshare ST-series Python control library.](https://files.waveshare.com/wiki/Bus_Servo_Driver_HAT_A/SCServo_Linux.rar) This will be the code that will help you setup the serial bus servos. Download onto a predetermined location, and then run `unrar x SCServo_Linux.rar` This will unzip the file, allowing for setup. Then, run `sudo apt install cmake -y` CMake will be the application that actually sets up your code and allows you to control the servos.
    6. Then, open your SCServoLinux file in a new terminal (right click the SCServoLinux file -inside the SCServoLinux_220329, and then click "Open in Terminal"). Then, run `cmake .` Then, run `make SCServo` It should say "[100%] Built target SCServo"
    7. Then, type in `cd examples/SMS_STS/WritePos` Run `nano WritePos.cpp` Change the 17th line to say "1000000" instead of "115200." This is the servo's baud rate, and it is 1000000 (the hardcoded value is wrong). Run Ctrl+O, click Enter, then run Ctrl+X. Now, you may run `cmake .` and then `make WritePos`
    8. Go back to the port from Step 2. Run `sudo ./WritePos [port]`, where your final command should look like `sudo ./WritePos /dev/ttyACM2` When you want this to stop, you can run Ctrl+C. Your servo should spin.



5. Setting up __THE SECOND__ Servo:
    1. Disconnect power from the serial bus servo adapter and the USB-C cable connecting the board to the Pi. Once power is off, disconnect the first serial bus servo and replace it for the one labeled "2" and wire that.
    2. Run `mkdir ~/SCServo_Linux_220329/SCServo_Linux/examples/SMS_STS/ChangeID` Find the ChangeID.cpp file attached above and drop it into the newly created ChangeID folder.
    3. Run:
       ```
       cp ~/SCServo_Linux_220329/SCServo_Linux/examples/SMS_STS/WritePos/CMakeLists.txt \
       ~/SCServo_Linux_220329/SCServo_Linux/examples/SMS_STS/ChangeID/
       cd ~/SCServo_Linux_220329/SCServo_Linux/examples/SMS_STS/ChangeID
       sed -i 's/WritePos/ChangeID/g' CMakeLists.txt
       ```
       and then run, in the ChangeID folder:
       ```
       cmake .
       make
       sudo ./ChangeID /dev/[port]
       ```
       Where [port] is in the format "ttyACM0".
    4. Run `nano WritePos.cpp` and check if "sm_st.WritePosEx" has the number 2 following it. This is the ID the Pi will ping. If it is not 2, change it to be 2 (ONLY IF YOU DID CHANGE THE NUMBER, run Ctrl+O, Enter, Ctrl+X. Then, open the WritePos file in a separate terminal and run `cmake .`, then `make`). Then, run `sudo ./WritePos /dev/[port]` Your second servo should know spin.
6. Setting up __SUBSEQUENT__ Servos:
    1. Disconnect power from the serial bus servo adapter and the USB-C cable connecting the board to the Pi. Once power is off, disconnect the first serial bus servo and replace it for the next labeled servo and wire that.
    2. Run `nano ChangeID.cpp` in the ChangeID folder terminal and change the `#define NEW_ID 2` to have your new number replacing the 2 (or whatever other number is there). Ctrl+O, Enter, Ctrl+X, and in that same terminal, run `cmake .` `make` and finally `sudo ./ChangeID /dev/[port]`
    3. Run `nano WritePos.cpp` in the WritePos folder terminal and change the `WritePosEx` command to have your new ID number. Ctrl+O, Enter, Ctrl+X, run `cmake .` `make` and finally `sudo ./WritePos /dev/[port]` so that your newest servo spins.
  
Yes, you should label your servos.

See how nice and easy that looks?

7. Setting up the US-100s:
    1. Run `sudo apt full-upgrade` and then `sudo apt install gpiod` Then, run `sudo apt install python3-gpiozero`
    2. Run `gpiodetect` and check the "gpiochip" that has "pinctrl-rp1". For most boots, this is "gpiochip0." Since I have the version of the pi with this boot, I have saved the code to run with chip=0. If you have a different gpio chip connected to "pinctrl," change the provided code to have that chip number at the 6th line's `chip=` section.
    3. Remove the black jumper out of each US-100 sensor (this is because we will be using each in "HC-SR04" mode, NOT UART mode. Then wire EACH sensor with the following arrangement (pull up a GPIO pin layout for the Raspberry Pi online while setting up), noting that since all three are on different GPIO pins, you may connect all three sensors at the same time to fully test sensor capability:

       a. The first sensor should have its VCC port connected to PIN 1, one of its ground ports connected to PIN 9, its Trig/TX pin connected to GPIO 5 OR PIN 29, and its Echo pin connected to GPIO 6 or PIN 31.
       
       b. The second sensor should have its VCC port connected to PIN 17, one of its ground ports connected to PIN 6, its Trig/TX pin connected to GPIO 17 or PIN 11, and its Echo pin connected to GPIO 27 or PIN 13.
       
       c. The third sensor should have its VCC port connected to PIN 2, one of its ground ports connected to PIN 14, its Trig/TX pin connected to GPIO 23 or PIN 16, and its Echo pin connected to GPIO 24 or PIN 18.

       

    5. Through the top left of the desktop, open programming and then Thonny. Copy/paste the following code into it.
        ```
        import time
        from gpiozero import DistanceSensor
        from gpiozero.pins.lgpio import LGPIOFactory
        
        # Run gpiodetect, whichever chip has "pinctrl" associated with it is the chip below
        factory = LGPIOFactory(chip=0)
        
        sensors = {
            "left":   DistanceSensor(echo=6,  trigger=5,  pin_factory=factory, max_distance=4.5),
            "center": DistanceSensor(echo=27, trigger=17, pin_factory=factory, max_distance=4.5),
            "right":  DistanceSensor(echo=24, trigger=23, pin_factory=factory, max_distance=4.5),
        }

        def read_all():
            # Time sleep meant to eliminate cross-talk
            readings = {}
            for name, sensor in sensors.items():
                readings[name] = sensor.distance * 100
                time.sleep(0.03)
            return readings

        if __name__ == "__main__":
            try:
                while True:
                    readings = read_all()
                    print(
                        f"L: {readings['left']:.1f}cm  "
                        f"C: {readings['center']:.1f}cm  "
                        f"R: {readings['right']:.1f}cm"
                    )
                    time.sleep(0.1)
            except KeyboardInterrupt:
                pass
        ```
    7. Run the code. You should now have working ultrasonic sensors. If this works, you're all set up for any of the later code! If one does not work, wire it individually in the same configuration to troubleshoot. Common errors involve incorrect wiring (ie, wrong gpio pins are connected OR each DuPont connector is improperly secured) and/or failing to download the correct modules/copying the proper code. This works on the Pi 5 ONLY; older, outdated modules like pigpio are necessary for older models.



Hopefully, your screen is not very different or far away from this.

P.S, if everything seems like a wired mess, do NOT fret.



Hopefully both of us can fix this eventually.

[To be continued]. If ANY of the steps above return an error or an issue in setup, you may contact me at chaitanyag2612@gmail.com for support.

[Go back home.](/README.md)

[Onto the next tutorial!](/docs/wiring.md)

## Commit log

2026-07-15 Files to be 3D Printed
    I have made all of the parts to fit into a 256 mm^3 build plate, the first 8 files conveniently named BuildPlate_ASA#1-8 are all to be printed in ASA with an infill of 60% with the sole exception of BuildPlate_ASA#5 which is the main chassis and can be printed with an infill of 40%. Also you might notice that BuildPlate_ASA#1 and BuildPlate_ASA#2 are the same, that is no mistake, I just copied them to make it easier (or harder I guess for some people). BuildPlate_TPU#1-2 are meant to be printed in TPU with an infill of 30%, note that while both may have wheels they are slightly different so do NOT copy it and print it again.
    [BuildPlate_ASA#1.step, BuildPlate_ASA#2.step, BuildPlate_ASA#3.step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]
2026-07-15 Update README with printing instructions and infill details
    Added printing instructions for BuildPlate files and clarified infill requirements for different components.
2026-07-15 Fix typo in instructions to print section
    Corrected a typo in the instructions section of the README.
2026-07-15 Update printing instructions in README
    Clarified printing instructions for BuildPlate_ASA files, including infill percentages for BuildPlate_ASA#9.
2026-07-20 Uploading the BOM, as a CSV, XLSX, and a PDF
    [Rover-BOM.csv, Rover-BOM.xlsx]
2026-07-20 Organizing, BOM
    [Rover-BOM.xlsx]
2026-07-20 ASA Prints, Organizing
    [BuildPlate_ASA#1.step]
2026-07-20 TPU Prints, Organizing
    [BuildPlate_TPU#1.step]
2026-08-05 Enhance rover features and update README instructions
    Expanded the rover's capabilities to include object detection, remote control, and autonomous travel. Added detailed instructions for printing, wiring, and future coding updates.
2026-08-05 Updating Files, adding STEPs/STLs/Final Assembly
    [ASA_#1_60%_4-walls.stl, ASA_#2_60%_4-walls.stl, ASA_#3_60%_4-walls.stl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]
2026-08-09 Adding 3MF Files
    [ASA_#1_20%_3d-cubic_2walls.3mf, ASA_#2_20%_3d-cubic_2walls.3mf, ASA_#3_20%_3d-cubic_2walls.3mf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]
2026-08-09 Updating Files
    [ASA_#1_60%_4-walls.stl, ASA_#2_60%_4-walls.stl, ASA_#3_60%_4-walls.stl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]
2026-08-09 Uploading Updated BOM
    [BOM.csv]
2026-08-09 Enhance README with additional sections and details
    Added sections for Hack-Club Q&A, screenshots, BOM, printing instructions, wiring instructions, and coding instructions.
2026-08-13 Update README with Raspberry Pi setup instructions
    Added detailed instructions for setting up the Raspberry Pi and VK-162 GPS device, including software installation and configuration steps.
2026-08-14 Revise setup instructions for Raspberry Pi AI Camera
    Updated instructions for setting up the Raspberry Pi AI Camera, including wiring details and commands for live feed and post-processing.
2026-08-15 Enhance README with additional supplies and setup details
    Updated instructions and added recommended supplies for Raspberry Pi setup.
2026-08-15 Attaching ChangeID.cpp
    Allows the Pi to write an ID to the serial bus servo connected.
2026-08-15 Revise servo setup instructions in README
    Updated instructions for setting up the second servo and subsequent servos, including detailed steps for changing IDs and running commands.
2026-08-15 Fixed Modifier 3mfs
    [TPU_#1_15%_gyroid_6wallsmodifiers_2walls.3mf]
2026-08-16 Fix spelling error in README.md
    Corrected spelling of 'attach' in the README.
2026-08-16 Update README with solderless build note and wiring details
    Added a note about the build being solderless and updated wiring instructions.
2026-08-16 Updating ASA#4 file to have updated Camera Mount
    See above.
    [ASA_#4_20%_3d-cubic_2walls.3mf]
2026-08-17 Revise US-100 sensor setup and code examples
    Updated wiring instructions and code for US-100 sensors to allow simultaneous connection and troubleshooting steps for ultrasonic sensors.
2026-08-19 Update printing instructions in printing.md
    Added detailed printing instructions and settings for 3MF and TPU files, including infill recommendations and expected filament usage.
2026-08-19 Add update note for assembly documentation
    Add placeholder for future updates regarding prints.
2026-08-19 Document Raspberry Pi setup and peripheral configuration
    Added detailed setup instructions for Raspberry Pi and peripherals, including steps for configuring servos and ultrasonic sensors.
2026-08-19 Update setup instructions for clarity
    Clarified the timing of the setup step in relation to wiring.
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2026-08-19 Document wiring instructions for solderless rover setup
    Added detailed wiring instructions and diagrams for the rover.
2026-08-19 Revise README for clarity and organization
    Updated the README to correct typos, enhance clarity, and reorganize sections for better navigation. Added links to documentation for printing, wiring, and assembly instructions.
2026-08-19 Update wiring instructions section in README
    Removed redundant image links and simplified teaser text.
2026-08-19 Enhance wiring documentation with safety and setup details
    Added detailed wiring instructions and safety warnings for circuit setup, including power injection and component connections.
2026-08-19 Revise wiring documentation for clarity and detail
    Updated recommendations for assembly and electronics setup.
2026-08-19 Enhance wiring instructions with wire stripping tips
    Added detailed instructions for wire stripping and crimping techniques to ensure proper connections.
2026-08-19 Update README with final assembly link
    Added a link to the final assembly in the README.
2026-08-19 Add navigation links in printing.md
    Added links to navigate back home and to the next tutorial.
2026-08-19 Fix link to go back home in printing.md
2026-08-19 Fix link to README in printing.md
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2026-08-23 Updating files for new prints
    [ASA_#6_20%_3d-cubic_2walls.3mf, ASA_#9_20%_3d-cubic_4walls.3mf, ASA_#9_50%_3d-cubic_4walls.3mf]
2026-08-23 Update images for ASA #6 and ASA #9
    Replaced images for ASA #6 and ASA #9 in printing documentation.
2026-08-23 Correct ASA weight and printing duration details
    Updated ASA usage and printing time estimates.
2026-08-25 Enhance wiring instructions with diagrams
    Added wiring diagrams and brief instructions for the rover.
2026-08-25 Update wiring diagrams in documentation
    Replaced the third wiring diagram with a new image.
2026-08-27 Updating ASA #4
    [ASA_#4_20%_3d-cubic_2walls.3mf]
2026-08-27 Fix ASA weight in printing documentation
    Corrected the weight of ASA used in printing estimates.
2026-09-08 Revise BOM with updated item costs and details
    Updated the Bill of Materials (BOM) with revised costs and descriptions for various items. Adjusted the total cost to include taxes and shipping.
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
